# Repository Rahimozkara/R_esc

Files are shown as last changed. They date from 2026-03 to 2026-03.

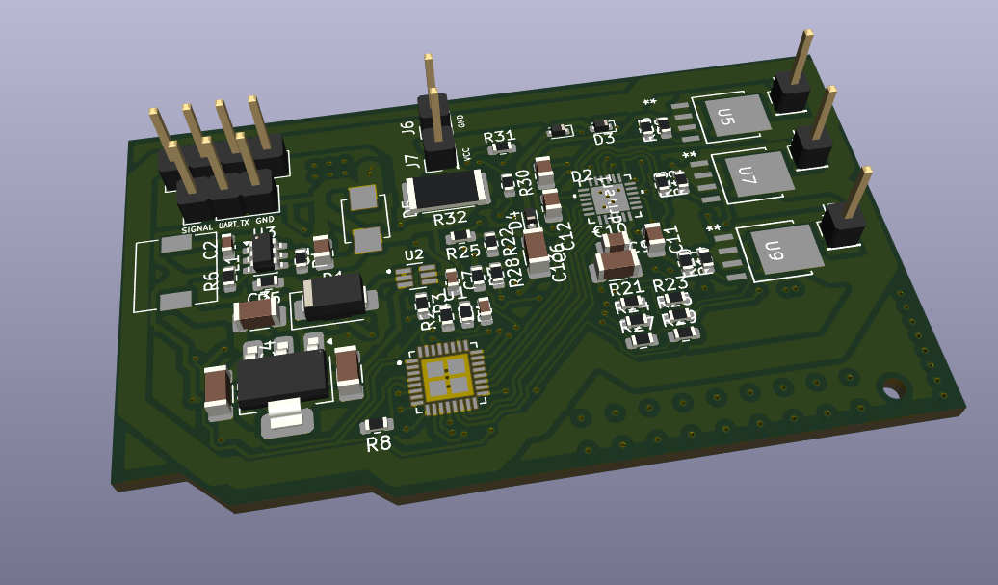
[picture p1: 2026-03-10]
Images/Ekran görüntüsü 2026-03-10 211703.png

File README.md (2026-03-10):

AM32 Single ESC
⚠️ Disclaimer & Project Status: This is an educational project designed by an engineering student. Please note that the current hardware revision has not yet been physically tested. Manufacture, flash, and use at your own risk.

📖 About the Project
This is an open-source, high-performance single Electronic Speed Controller (ESC) designed for FPV drones and custom robotics. It is fully compatible with the AM32 firmware, providing smooth and efficient brushless DC (BLDC) motor control.

✨ Features
Firmware: AM32 Open Source Firmware

Microcontroller: STM32F051

Estimated Continuous Current: ~20A

Supported Protocols: DShot300 / DShot600 / PWM

Application: FPV Drones & Custom Robotics

🛠️ Hardware Design & Known Issues
The schematic and PCB layout for this project were designed using KiCad. The board layout is optimized for efficient power delivery and stable thermal dissipation.

🛑 Important Hardware Note (Current Sensing):
In the current schematic, an INA199A1DCKR current sense amplifier is used, which features a gain of 50 V/V. However, the default AM32 firmware code expects a current sensor with a gain of 65 V/V.

Recommendation: To ensure accurate current readings, you must either adjust the multiplier in the AM32 firmware code to account for the 50x gain, or replace this IC with a 65x gain variant in future PCB revisions.

🚀 How to Manufacture
All necessary hardware files for manufacturing are included in this repository. You can directly use the provided Gerber files for PCB fabrication.

💻 Flashing & Setup
Initial firmware flashing can be done via the SWD pads located on the board using an ST-Link. Once the bootloader is installed, further firmware updates and configuration can be easily managed via Betaflight passthrough.

📄 License
This project is open-source. Feel free to use, modify, and contribute! 
Ekran görüntüsü 2026-03-10 211703

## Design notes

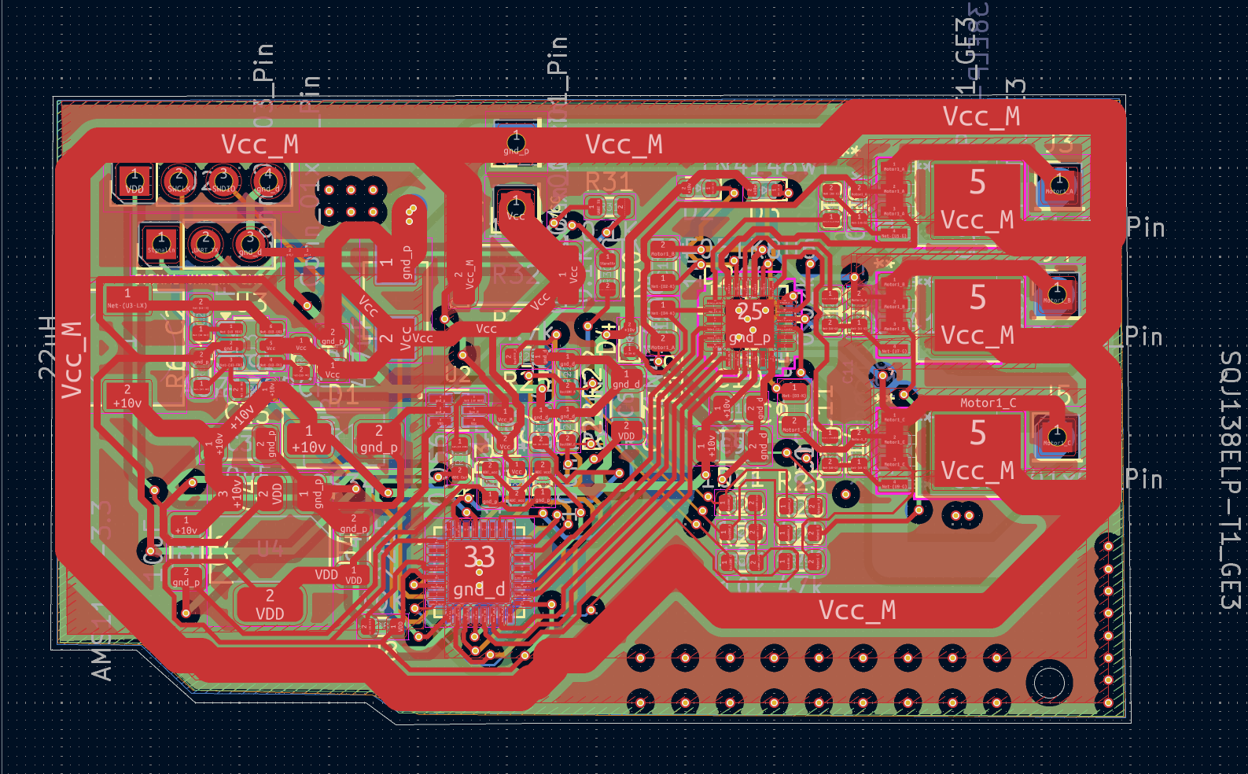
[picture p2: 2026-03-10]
Images/Ekran görüntüsü 2026-03-10 211632.png

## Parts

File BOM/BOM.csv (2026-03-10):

Reference(s) | Quantity | Value / Name | Footprint | Type
U1 | 1 | STM32F051K8U6 | QFN50P500X500X60-33N | Microcontroller
driver1 | 1 | FD6288Q | QFN24_FOR-M | Gate Driver
U5, U6, U7, U8, U9, U10 | 6 | SQJ138ELP-T1_GE3 | PowerPAK_SO-8L_3_VIS | N-Channel MOSFET
U2 | 1 | INA199A1DCKR | SOT65P210X110-6N | Current Sense Amplifier (Gain: 50)
U3 | 1 | AOZ1282CI | SOT-23-6 | Voltage Regulator (Buck)
U4 | 1 | AMS1117-3.3 | SOT-223-3_TabPin2 | LDO Regulator (3.3V)
D1 | 1,"SS34" | D_SMA | Schottky Diode
D2, D3, D4 | 3 | 1N4148WT | D_SOD-523 | Signal Diode
D5 | 1,"SMBJ30CA" | DIOM4336X265N | TVS Diode
C4, C6 | 2 | 22uF | C_1206_3216Metric | Capacitor
C3, C5, C9 | 3 | 10uF | C_1206_3216Metric | Capacitor
C1 | 1 | 4.7uF | C_0805_2012Metric | Capacitor
C10, C11, C12, C13 | 4 | 1uF | C_0805_2012Metric | Capacitor
C8 | 1 | 100nF | C_0603_1608Metric | Capacitor
C2 | 1 | 0.1uF | C_0603_1608Metric | Capacitor
C7 | 1 | 1nF | C_0603_1608Metric | Capacitor
R1, R4 | 2 | 100K | R_0603_1608Metric | Resistor
R23, R26, R29 | 3 | 47k | R_0603_1608Metric | Resistor
R5 | 1 | 39k | R_0603_1608Metric | Resistor
R2, R7, R8, R15, R16, R17, R18, R19, R20, R21, R24, R27 | 12 | 10K | R_0603_1608Metric | Resistor
R22, R25, R28 | 3 | 4.7k | R_0603_1608Metric | Resistor
R6 | 1 | 3.3K | R_0603_1608Metric | Resistor
R30, R31 | 2 | 0.1K | R_0603_1608Metric | Resistor
R3 | 1 | 0.056k | R_0603_1608Metric | Resistor
R9, R10, R11, R12, R13, R14 | 6 | 0.02k | R_0603_1608Metric | Resistor (Gate)
R32 | 1 | 1mR | R_2512_6332Metric | Shunt Resistor
L1 | 1 | 22uH | L_6.3x6.3_H3 | Inductor
J2 | 1 | Conn_01x04_Pin | PinHeader_1x04_P2.54mm_Vertical | Connector
J1 | 1 | Conn_01x03_Pin | PinHeader_1x03_P2.54mm_Vertical | Connector
J3, J4, J5, J6, J7 | 5 | Conn_01x01_Pin | PinHeader_1x01_P2.54mm_Vertical | Connector (Single Pin)
NT1 | 1 | NetTie_2 | NetTie-2_SMD_Pad0.5mm | Net Tie

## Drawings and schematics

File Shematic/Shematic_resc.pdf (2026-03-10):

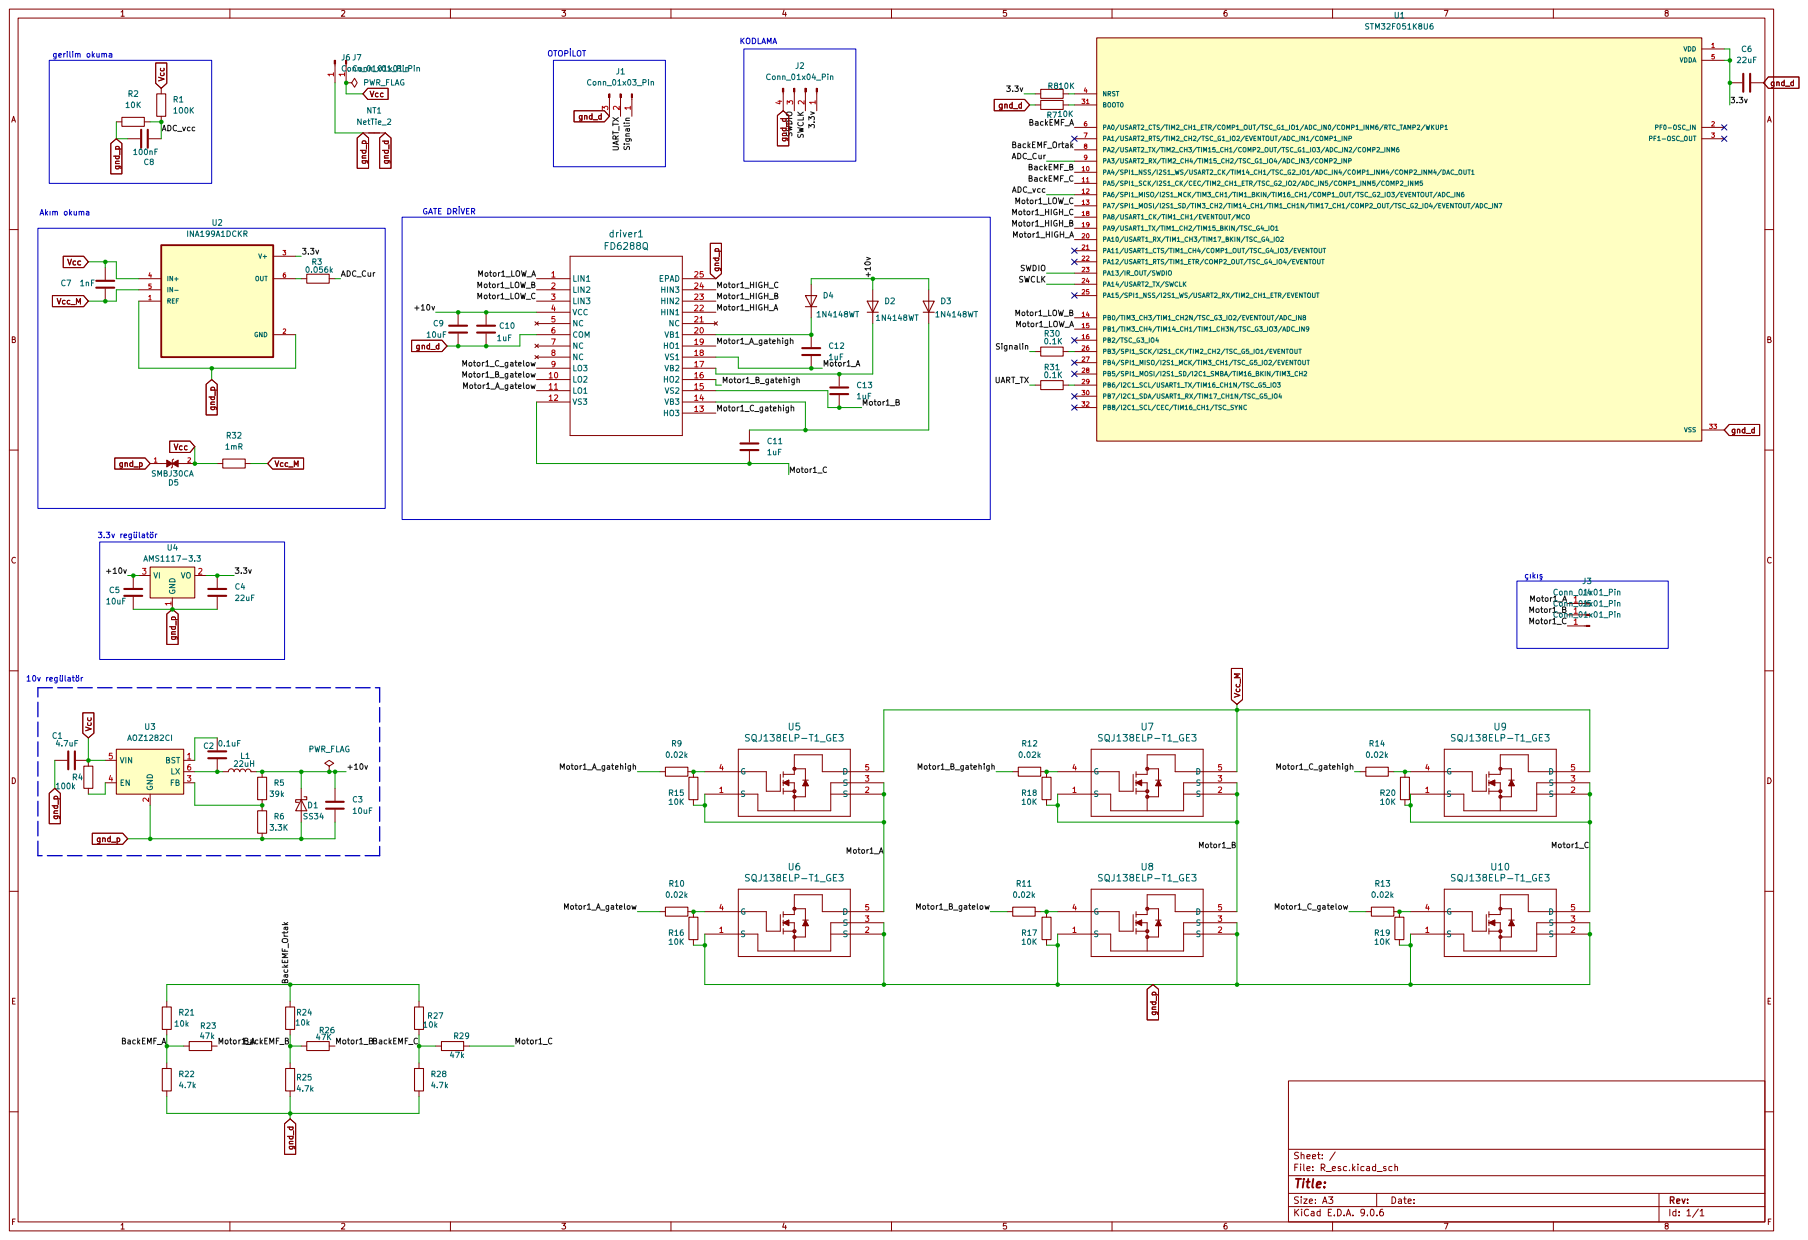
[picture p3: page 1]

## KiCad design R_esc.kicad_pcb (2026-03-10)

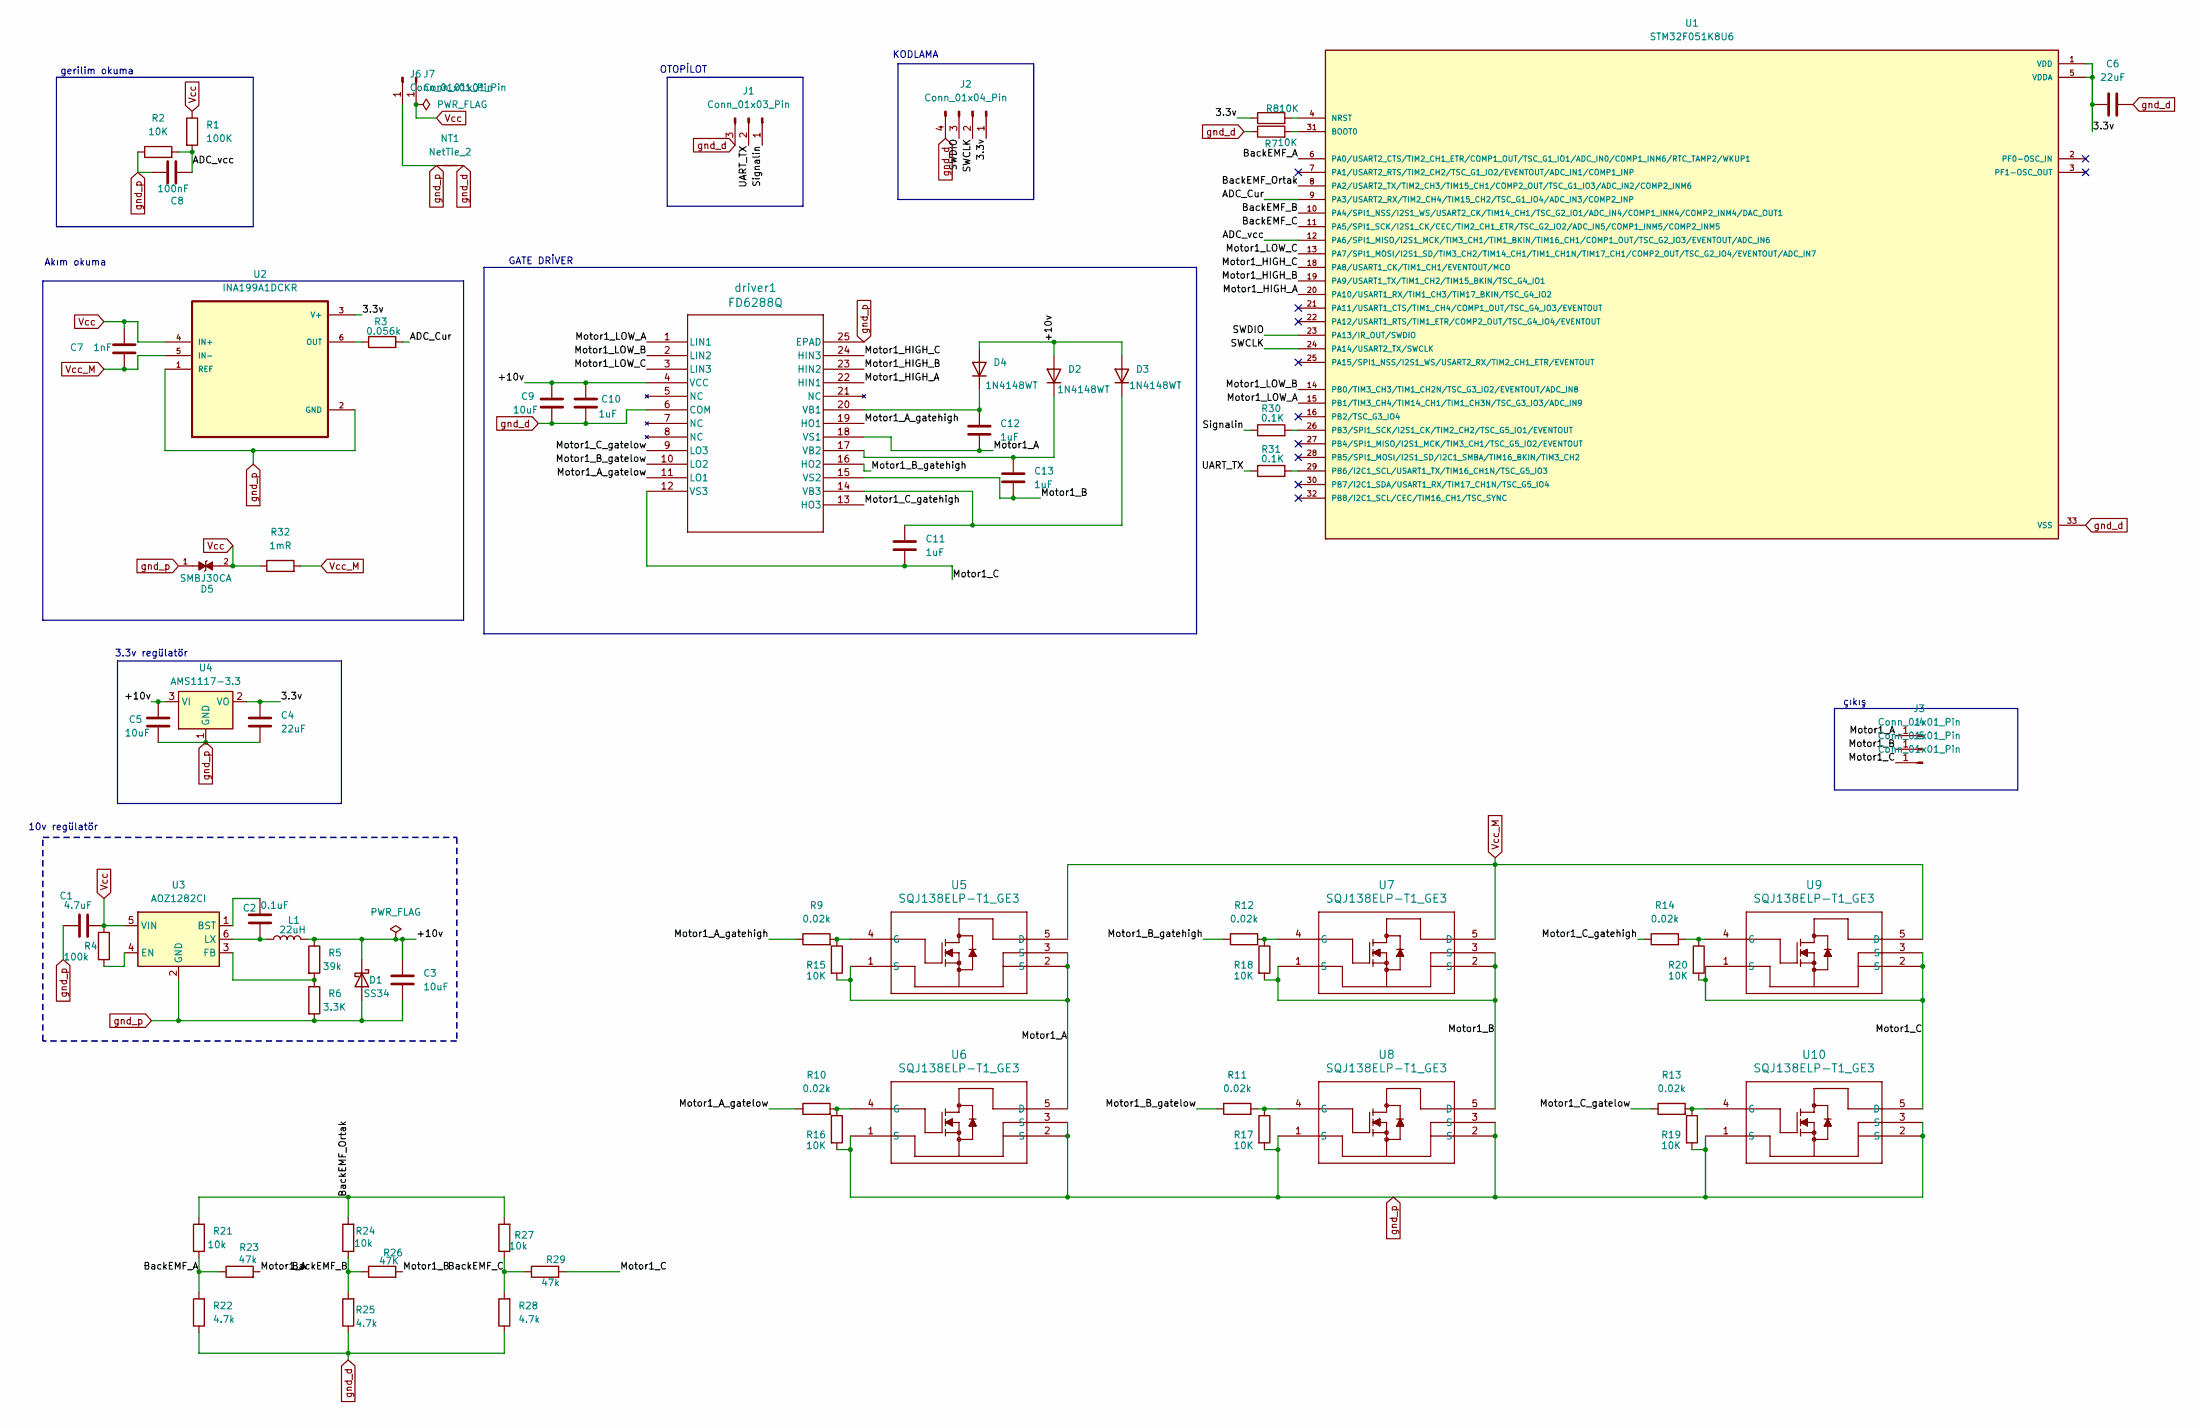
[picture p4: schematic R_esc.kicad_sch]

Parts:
C1: 4.7uF; C_0805_2012Metric
C2: 0.1uF; C_0603_1608Metric
C3, C5, C9: 10uF; C_1206_3216Metric
C4, C6: 22uF; C_1206_3216Metric
C7: 1nF; C_0603_1608Metric
C8: 100nF; C_0603_1608Metric
C10, C11, C12, C13: 1uF; C_0805_2012Metric
D1: SS34; D_SMA
D2, D3, D4: 1N4148WT; D_SOD-523
D5: SMBJ30CA; DIOM4336X265N; PARTREV I2102
J1: Conn_01x03_Pin; PinHeader_1x03_P2.54mm_Vertical
J2: Conn_01x04_Pin; PinHeader_1x04_P2.54mm_Vertical
J3, J4, J5, J6, J7: Conn_01x01_Pin; PinHeader_1x01_P2.54mm_Vertical
L1: 22uH; L_6.3x6.3_H3
NT1: NetTie_2; NetTie-2_SMD_Pad0.5mm
R1: 100K; R_0603_1608Metric
R2, R7, R8, R15, R16, R17, R18, R19, R20: 10K; R_0603_1608Metric
R3: 0.056k; R_0603_1608Metric
R4: 100k; R_0603_1608Metric
R5: 39k; R_0603_1608Metric
R6: 3.3K; R_0603_1608Metric
R9, R10, R11, R12, R13, R14: 0.02k; R_0603_1608Metric
R21, R24, R27: 10k; R_0603_1608Metric
R22, R25, R28: 4.7k; R_0603_1608Metric
R23, R29: 47k; R_0603_1608Metric
R26: 47K; R_0603_1608Metric
R30, R31: 0.1K; R_0603_1608Metric
R32: 1mR; R_2512_6332Metric
U1: STM32F051K8U6; QFN50P500X500X60-33N; PARTREV 7
U2: INA199A1DCKR; SOT65P210X110-6N
U3: AOZ1282CI; SOT-23-6
U4: AMS1117-3.3; SOT-223-3_TabPin2
U5, U6, U7, U8, U9, U10: SQJ138ELP-T1_GE3; PowerPAK_SO-8L_3_VIS
driver1: FD6288Q; QFN24_FOR-M

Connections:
/+10v: C3.1, C5.1, C9.1, C10.1, D1.1 (K), D2.2 (A), D3.2 (A), D4.2 (A), L1.2, R5.1, U4.3 (VI), driver1.4 (VCC)
/ADC_Cur: R3.2, U1.9 (PA3/USART2_RX/TIM2_CH4/TIM15_CH2/TSC_G1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)
/ADC_vcc: C8.2, R1.2, R2.2, U1.12 (PA6/SPI1_MISO/I2S1_MCK/TIM3_CH1/TIM1_BK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)
/BackEMF_A: R21.1, R22.2, R23.1, U1.6 (PA0/USART2_CTS/TIM2_CH1_ETR/COMP1_OUT/T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)
/BackEMF_B: R24.1, R25.2, R26.1, U1.10 (PA4/SPI1_NSS/I2S1_WS/USART2_CK/TIM14_CH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)
/BackEMF_C: R27.1, R28.2, R29.1, U1.11 (PA5/SPI1_SCK/I2S1_CK/CEC/TIM2_CH1_ETR/T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)
/BackEMF_Ortak: R21.2, R24.2, R27.2, U1.8 (PA2/USART2_TX/TIM2_CH3/TIM15_CH1/COMP2_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)
/Motor1_A: C12.2, J3.1, R15.2, R23.2, U5.1 (S), U5.2 (S), U5.3 (S), U6.5 (D), driver1.18 (VS1)
/Motor1_A_gatehigh: R9.1, driver1.19 (HO1)
/Motor1_A_gatelow: R10.1, driver1.11 (LO1)
/Motor1_B: C13.2, J4.1, R18.2, R26.2, U7.1 (S), U7.2 (S), U7.3 (S), U8.5 (D), driver1.15 (VS2)
/Motor1_B_gatehigh: R12.1, driver1.16 (HO2)
/Motor1_B_gatelow: R11.1, driver1.10 (LO2)
/Motor1_C: C11.2, J5.1, R20.2, R29.2, U9.1 (S), U9.2 (S), U9.3 (S), U10.5 (D), driver1.12 (VS3)
/Motor1_C_gatehigh: R14.1, driver1.13 (HO3)
/Motor1_C_gatelow: R13.1, driver1.9 (LO3)
/Motor1_HIGH_A: U1.20 (PA10/USART1_RX/TIM1_CH3/TIM17_BKIN/TSC_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), driver1.22 (HIN1)
/Motor1_HIGH_B: U1.19 (PA9/USART1_TX/TIM1_CH2/TIM15_BKIN/TSC_G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), driver1.23 (HIN2)
/Motor1_HIGH_C: U1.18 (PA8/USART1_CK/TIM1_CH1/EVENTOUT/MCO), driver1.24 (HIN3)
/Motor1_LOW_A: U1.15 (PB1/TIM3_CH4/TIM14_CH1/TIM1_CH3N/TSC_G3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), driver1.1 (LIN1)
/Motor1_LOW_B: U1.14 (PB0/TIM3_CH3/TIM1_CH2N/TSC_G3_IO2/EVENT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), driver1.2 (LIN2)
/Motor1_LOW_C: U1.13 (PA7/SPI1_MOSI/I2S1_SD/TIM3_CH2/TIM14_CH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), driver1.3 (LIN3)
/SWCLK: J2.2, U1.24 (PA14/USART2_TX/SWCLK)
/SWDIO: J2.3, U1.23 (PA13/IR_OUT/SWDIO)
/Signalin: J1.1, R30.1
/UART_TX: J1.2, R31.1
unnamed: C13.1, D2.1 (K), driver1.17 (VB2)
unnamed: C11.1, D3.1 (K), driver1.14 (VB3)
unnamed: C12.1, D4.1 (K), driver1.20 (VB1)
unnamed: R7.2, U1.31 (BOOT0)
unnamed: R8.2, U1.4 (NRST)
unnamed: R30.2, U1.26 (PB3/SPI1_SCK/I2S1_CK/TIM2_CH2/TSC_G5_IO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)
unnamed: R31.2, U1.29 (PB6/I2C1_SCL/USART1_TX/TIM16_CH1N/TSC_G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)
unnamed: R3.1, U2.6 (OUT)
unnamed: C2.1, U3.1 (BST)
unnamed: R4.2, U3.4 (EN)
unnamed: R5.2, R6.1, U3.3 (FB)
unnamed: C2.2, L1.1, U3.6 (LX)
unnamed: R9.2, R15.1, U5.4 (G)
unnamed: R10.2, R16.1, U6.4 (G)
unnamed: R12.2, R18.1, U7.4 (G)
unnamed: R11.2, R17.1, U8.4 (G)
unnamed: R14.2, R20.1, U9.4 (G)
unnamed: R13.2, R19.1, U10.4 (G)
VDD: C4.1, C6.2, J2.1, R8.1, U1.1 (VDD), U1.5 (VDDA), U1.17 (VDD), U2.3 (V+), U4.2 (VO)
Vcc: C1.1, C7.2, D5.2, J7.1, R1.1, R4.1, R32.1, U2.4 (IN+), U3.5 (VIN)
Vcc_M: C7.1, R32.2, U2.5 (IN-), U5.5 (D), U7.5 (D), U9.5 (D)
gnd_d: C6.1, C9.2, C10.2, J1.3, J2.4, NT1.2, R7.1, R22.1, R25.1, R28.1, U1.33 (VSS), driver1.6 (COM)
gnd_p: C1.2, C3.2, C4.2, C5.2, C8.1, D1.2 (A), D5.1, J6.1, NT1.1, R2.1, R6.2, R16.2, R17.2, R19.2, U2.1 (REF), U2.2 (GND), U3.2 (GND), U4.1 (GND), U6.1 (S), U6.2 (S), U6.3 (S), U8.1 (S), U8.2 (S), U8.3 (S), U10.1 (S), U10.2 (S), U10.3 (S), driver1.25 (EPAD)

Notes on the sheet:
3.3v regülatör
10v regülatör
KODLAMA
GATE DRİVER
çıkış
gerilim okuma
Akım okuma
OTOPİLOT

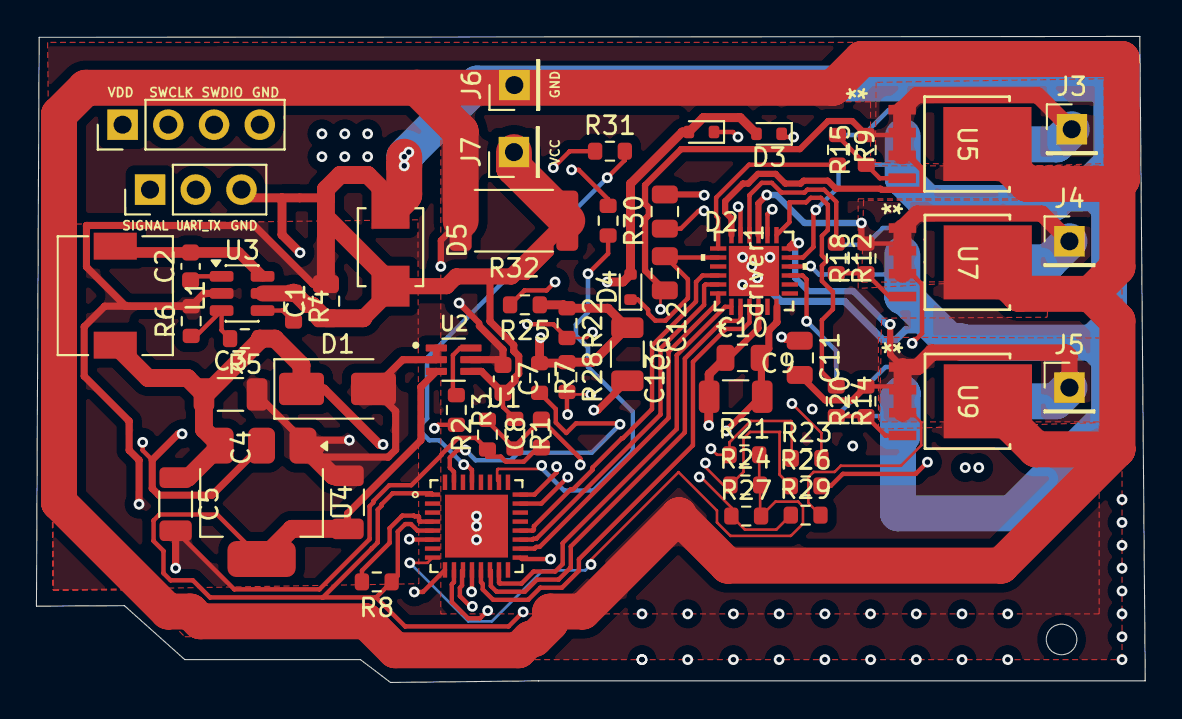
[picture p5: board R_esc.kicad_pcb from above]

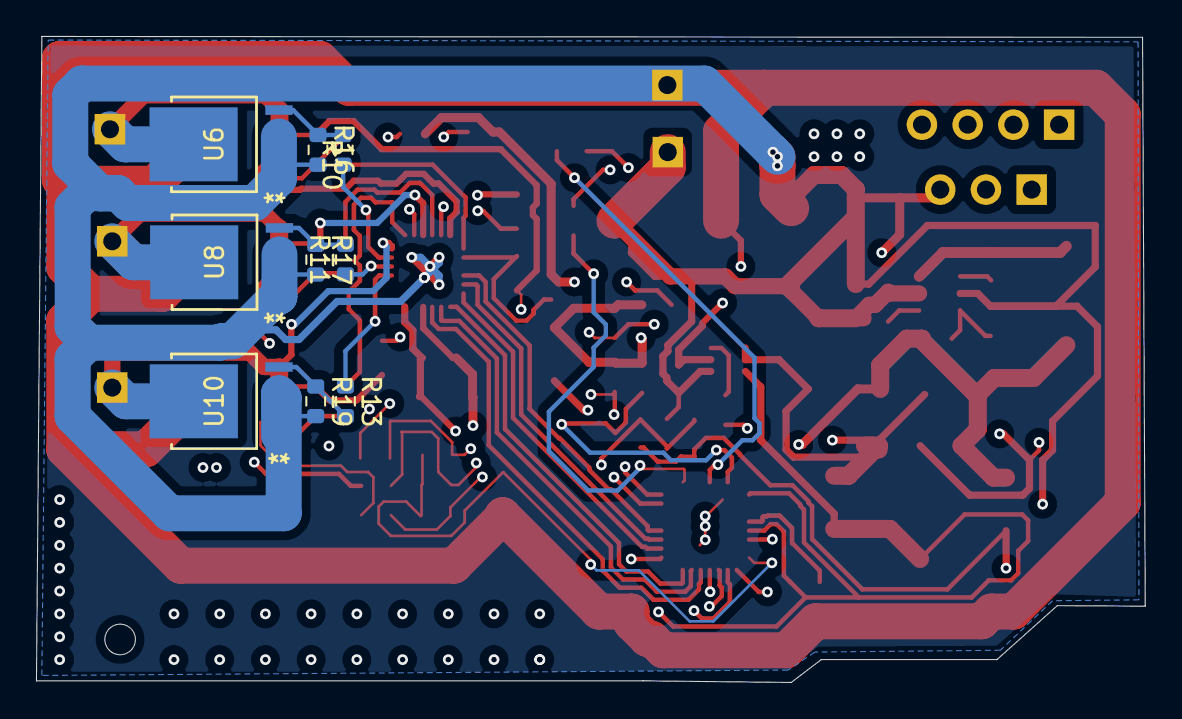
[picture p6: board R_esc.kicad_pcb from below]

Board: 4 copper layers, 61.6 x 35.9 mm, 70 parts (9 on the bottom side), 49 nets.

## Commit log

2026-03-07 ilk commit
    [R_esc.kicad_pcb, R_esc.kicad_sch]
2026-03-07 shema and footprints are mostly done
    [R_esc.kicad_sch]
2026-03-09 layout eklendi
    [R_esc.kicad_pcb, R_esc.kicad_sch]
2026-03-10 new commit
    [R_esc.kicad_pcb]
